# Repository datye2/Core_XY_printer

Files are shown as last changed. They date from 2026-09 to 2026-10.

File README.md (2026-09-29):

# CoreXY Printer

Bo điều khiển máy in 3D CoreXY và firmware tự viết cho nó. Không dùng Marlin, Klipper hay RepRapFirmware — toàn bộ từ parser tới bộ phát xung đều viết tay, chạy trên một MCU duy nhất.

## Phần cứng

| Thành phần | Lựa chọn |
|---|---|
| MCU | STM32H743IIT6, bo lõi FANKE FK743M2-IIT6 (480 MHz, HSE 25 MHz) |
| Driver X/Y | 2 × TMC2209, điều khiển qua UART một dây |
| Driver Z, E | 3 × A4988 (Z1, Z2, E) |
| Nguồn động lực | 24V |
| Công tắc hành trình | 3 cảm biến tiệm cận NPN, cách ly bằng PC817, Z kiêm dò bàn |
| MOSFET gia nhiệt | IRLB3034PbF, lái bằng TC4427 |

**Cơ khí:** đai GT2, puly 20 răng (40 mm mỗi vòng), vi bước 1/16 có nội suy, tức **80 bước/mm**.

## Cấu trúc thư mục

```
hardware/corexy_board/   sơ đồ KiCad 8 trang, BOM
hardware/tools/          script sinh và kiểm tra sơ đồ
software/CoreXY/         firmware STM32 (CubeMX + CMake)
  module/                code tự viết: tmc2209, stepper
  Core/                  code CubeMX sinh ra
  tools/flash_run.sh     nạp và chạy thử trong một lệnh
  debug/tmc.gdb          lệnh gdb hỗ trợ soi driver
docs/                    tài liệu dự án
```

Phần tự viết nằm hết trong `software/CoreXY/module/`. Mọi thứ khác trong `Core/` là do CubeMX sinh, chỉ sửa trong các vùng `USER CODE`.

## Sơ đồ chân chính

| Tín hiệu | Chân | Ghi chú |
|---|---|---|
| Motor A STEP / DIR | PD3 / PD4 | địa chỉ UART 0 (MS1 = 0, MS2 = 0) |
| Motor B STEP / DIR | PG9 / PG10 | địa chỉ UART 1 (MS1 = 1, MS2 = 0) |
| EN chung A + B | PA15 | mức thấp là bật |
| TMC UART | PB10 (TX qua 1k) + PB11 (RX) | USART3, một dây chung, có tiếng vọng |
| DIAG A / B | PD7 / PG11 | chưa dùng |
| LED báo sống | PH7 | nháy trong SysTick |

**Lưu ý:** MS1 và MS2 dùng làm địa chỉ UART, nên **vi bước phải cài qua UART**, không cài bằng chân được. Xem [docs/timer.md](docs/timer.md) và phần TMC2209 trong `module/tmc2209.c`.

## Build và nạp

```bash
cd software/CoreXY
cmake -S . -B build/Debug -G Ninja -DCMAKE_BUILD_TYPE=Debug   # lần đầu
cmake --build build/Debug
```

Nạp bằng OpenOCD với ST-Link:
```bash
openocd -f interface/stlink.cfg -f target/stm32h7x.cfg \
  -c "program build/Debug/CoreXY.elf verify reset" -c shutdown
```

Nạp rồi chạy thử một đoạn thẳng trong một lệnh:
```bash
./tools/flash_run.sh 20 0 20      # dx mm, dy mm, tốc độ mm/s
NOFLASH=1 ./tools/flash_run.sh 40 0 60
```

Debug trong VS Code: bấm F5, chọn **ST-Link (CoreXY)**. Live Watch đã bật sẵn, xem được biến trong lúc chip đang chạy.

## Tình trạng

| Phần | Tình trạng |
|---|---|
| Sơ đồ KiCad | Xong bản v0.1, chưa vẽ PCB |
| Cấu hình TMC2209 qua UART | Chạy thật, cả 2 driver |
| Phát xung một motor bằng timer | Xong |
| Hai motor, Bresenham, động học CoreXY | Xong, đã vẽ được hình vuông và hình tròn |
| Gia tốc hình thang | Chưa |
| Parser G-code | Chưa |
| Lookahead | Chưa |
| Homing, nhiệt độ, quạt | Chưa |

Chi tiết trong [docs/checklist.md](docs/checklist.md).

## Tài liệu

- [docs/timer.md](docs/timer.md) — bộ phát xung: timer, ngắt, Bresenham, ngân sách CPU.
- [docs/checklist.md](docs/checklist.md) — việc đã xong và việc còn lại.
- [docs/01_kinh_nghiem_tu_mach_tham_khao.md](docs/01_kinh_nghiem_tu_mach_tham_khao.md) — rút kinh nghiệm từ SKR2, Octopus Pro, Duet2, Prusa Buddy.

## Tham khảo

Đọc để học cách làm, không chép code: **grbl** (`planner.c`, `stepper.c`, `motion_control.c`), **grblHAL** (bản grbl có HAL, hỗ trợ STM32H7), **Marlin** (`planner.cpp`, `stepper.cpp`), **Klipper** (`kinematics/corexy.py`, `chelper/kin_corexy.c`), và app note **Atmel AVR446** về profile tốc độ động cơ bước.

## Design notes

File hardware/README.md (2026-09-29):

# Phần cứng bo điều khiển CoreXY

```
hardware/
├── corexy_board/              Project KiCad (mở corexy_board.kicad_pro bằng KiCad 10)
│   ├── corexy_board.kicad_sch Trang gốc: sơ đồ khối, quyết định thiết kế, bảng gán chân MCU
│   ├── 01_Nguon.kicad_sch     XT60, TVS, cầu chì, buck 5V, chống USB cấp ngược, NetTie GND
│   ├── 02_MCU.kicad_sch       2 header 2x28 của kit FK743M2-IIT6
│   ├── 03_Driver.kicad_sch    2x TMC2209 (MKS V2.0, UART) + 3x A4988 (Z1, Z2, E)
│   ├── 04_Heater.kicad_sch    TC4427 + IRLB3034 cho hotend, bed (+ MOSFET an toàn)
│   ├── 05_Quat.kicad_sch      2 kênh AO3400A + quạt bo luôn bật
│   ├── 06_NTC.kicad_sch       3 kênh NTC 100k
│   ├── 07_IO.kicad_sch        3 cổng cảm biến NPN cách ly PC817, cảm biến hết nhựa, UART SBC
│   ├── corexy.kicad_sym       Symbol riêng (header kit, TMC2209 MKS, module buck, power net)
│   ├── corexy_board.pdf       Bản in schematic
│   └── bom.csv                Danh sách linh kiện (gom theo giá trị)
└── tools/
    ├── gen_schematic.py       Mô tả mạch bằng Python -> sinh toàn bộ schematic
    ├── check_schematic.py     Chạy ERC + so netlist KiCad với kết nối mong muốn
    └── intent_netlist.json    Kết nối mong muốn (do gen_schematic.py ghi)
```

## Sửa mạch

Hai cách, **chọn một**:

1. **Sửa trong script** (khuyên dùng khi còn đổi nhiều): sửa `tools/gen_schematic.py`, rồi
   ```
   cd hardware/tools
   python3 gen_schematic.py && python3 check_schematic.py
   ```
   `check_schematic.py` phải báo `0 lỗi so khớp`.
2. **Sửa tay trong KiCad**: từ lúc này **không chạy lại** `gen_schematic.py` nữa, vì nó ghi đè toàn bộ file.

## Quy ước net

- `GND` logic, `PGND` công suất (heater, quạt, cảm biến 24V), `MGND` motor → nối nhau 1 điểm qua `NT1`, `NT2`.
- `+24V_BED` / `+24V_HEAT` / `+24V_FAN` / `+24V_MOT` / `+24V_VMOT` / `+24V_SENS`: các nhánh sau cầu chì.
- `+5V` từ buck; `+5V_KIT` sau diode, cấp cho kit; `+3V3` lấy từ ổn áp trên kit.
- Chân nguồn nằm ngang được nối bằng global label cùng tên net nguồn (KiCad tự gộp với power symbol).

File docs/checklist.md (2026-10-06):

# Checklist dự án

Cập nhật: 2026-10-06

## Phần cứng

- [x] Chọn linh kiện chính: FK743M2-IIT6, 2 × TMC2209, 3 × A4988, IRLB3034, TC4427
- [x] Rút kinh nghiệm từ SKR2, Octopus Pro, Duet2, Prusa Buddy (xem `01_kinh_nghiem_tu_mach_tham_khao.md`)
- [x] Sơ đồ KiCad v0.1, 8 trang, sinh bằng `hardware/tools/gen_schematic.py`
- [x] Bo mẫu hàn tay, chạy được UART và hai motor
- [ ] Rà lại sơ đồ sau khi bo mẫu chạy ổn
- [ ] Vẽ PCB
- [ ] Đặt gia công và ráp bo thật

### Bài học từ bo mẫu, phải áp vào PCB

- **VIO của TMC2209 lấy 3.3V**, cùng mức với MCU. Cấp 5V thì ngưỡng mức 1 thành 3.5V, MCU xuất 3.3V không đủ.
- **Điện trở nối TX vào bus UART là 1k.** Thử 10k thì sườn tín hiệu chậm, phản hồi của driver về bị lệch bit.
- **Chân PDN_UART trên module StepStick có thể để hở**, phải hàn pad thì mới dùng UART được. Đây là thứ làm mất nhiều thời gian nhất khi dựng bo mẫu.
- **Dây SWD phải ngắn và xoắn với GND.** Chạy motor ở 80 mm/s từng làm đứt kết nối SWD và ST-Link rớt khỏi USB.

## Firmware

### Bước 0 — TMC2209 qua UART ✅

- [x] Driver UART một dây, xử lý tiếng vọng, CRC theo datasheet
- [x] Cấu hình GCONF (`pdn_disable`, `mstep_reg_select`, `i_scale_analog`)
- [x] Đặt vi bước 1/16 qua CHOPCONF.MRES, bật `intpol`
- [x] SENDDELAY = 2 vì có hai driver chung bus
- [x] Xác nhận lệnh ghi bằng IFCNT, kiểm tra chip bằng IOIN VERSION = 0x21
- [x] Timeout và khoảng nghỉ giữa gói tự tính theo baud
- [ ] Tự phát hiện driver bị reset (GSTAT bit 0) rồi nạp lại cấu hình
- [ ] Đặt dòng bằng phần mềm qua IHOLD_IRUN, thay cho biến trở VREF
- [ ] Chuyển sang SpreadCycle hoặc đặt TPWMTHRS khi chạy nhanh

### Bước 1 — Một motor bằng timer ✅

- [x] TIM2 ở 1 MHz, ngắt update
- [x] `stepper_move_a` với số bước và tốc độ
- [x] Đếm vị trí tuyệt đối, tự dừng khi hết bước
- [x] LED vẫn nháy khi motor quay, chứng tỏ CPU không bị chặn

### Bước 2 — Hai motor, Bresenham, CoreXY ✅

- [x] `stepper_move_xy(dx, dy, speed)` với phép biến đổi A = X+Y, B = X−Y
- [x] Bresenham trên một timer chung, hai motor cùng bắt đầu và cùng kết thúc
- [x] Chu kỳ tính theo chiều dài XY, không theo AB
- [x] Tính số bước từ đích tuyệt đối để không tích luỹ sai số
- [x] Bỏ vòng chờ trong ngắt, dùng compare channel CC1 hạ chân STEP
- [x] Ép sự kiện update khi nạp ARR vì ARR có preload
- [x] Thử thật: đường thẳng, hình vuông, hình tròn 72 đoạn, tất cả về đúng điểm xuất phát
- [ ] Đo lại tốc độ tối đa sau khi sửa ISR (lần trước đứt SWD ở 80 mm/s)

### Bước 3 — Gia tốc hình thang ✅

- [x] Mỗi block có 3 pha: tăng tốc, chạy đều, giảm tốc
- [x] Tính profile ngoài ngắt, trong ngắt chỉ còn truy hồi số nguyên AVR446
- [x] Biến dư giữ phần lẻ của phép chia nên sai số không tích luỹ
- [x] Đoạn ngắn tự chuyển thành profile tam giác
- [x] Trần 40 kHz mỗi motor, tốc độ vô lý bị trả về `STEPPER_ERROR`
- [x] `stepper_set_accel()`, mặc định 2000 mm/s²
- [x] Chạy thật 100 mm ở 150 mm/s hết 728 ms, khớp mô phỏng

### Bước 4 — Nhận lệnh 🔶

- [x] Parser `G0`, `G1`, `G2`, `G3`, `G4`, `G90`, `G91`, `G92`, `G21`, và `F`
- [x] Bỏ qua Z, E, M, S, T, N để file của slicer vẫn chạy được trên máy chỉ có XY
- [x] Bỏ chú thích `;` và `( ... )`
- [x] Tách lớp `motion_control`: `mc_line`, `mc_arc`, giữ vị trí tuyệt đối
- [x] `mc_arc` chia cung theo dung sai dây cung 0.002 mm, giống `mc_arc` của grbl
- [x] `tools/make_gcode.py` sinh file demo, `tools/gcode_to_header.py` nhúng vào flash
- [x] Chạy thật: 48 dòng, 0 lỗi, 9.4 giây, về đúng gốc
- [ ] Nhận lệnh qua UART hoặc USB CDC thay vì nhúng vào flash
- [ ] Trả `ok` sau mỗi dòng để host biết nhịp gửi
- [ ] Đọc file từ thẻ microSD

### Bước 5 — Hàng đợi và lookahead ✅

- [x] Ring buffer 16 block, producer là main loop, consumer là ngắt
- [x] Junction deviation kiểu grbl, `stepper_set_junction_deviation()`, mặc định 0.05 mm
- [x] Quét lùi rồi quét tới, không đụng block đang chạy
- [x] Nạp block kế tiếp ngay trong ngắt, timer không dừng giữa hai block
- [x] `i_offset`, `j_offset` nối liền đường dốc qua ranh giới block
- [x] Chạy thật: 100 mm chia 20 đoạn hết **728 ms**, bằng đúng khi đi một đoạn liền
- [ ] Đo lại trên đường tròn 72 dây cung (mô phỏng cho thấy nhanh hơn 3.6 lần)

### Sau đó ⬜

- [ ] Homing với 3 cảm biến tiệm cận, Z kiêm dò bàn
- [ ] Trục Z và đầu đùn trên A4988
- [ ] Đọc nhiệt độ NTC, vòng điều khiển PID cho hotend và bàn
- [ ] Điều khiển quạt
- [ ] Đọc file từ thẻ microSD
- [ ] Input shaping
- [ ] Chuyển phần planner sang SBC (dự tính xa)

## Công cụ và tài liệu

- [x] Build bằng CMake và Ninja
- [x] Debug VS Code với ST-Link qua OpenOCD, bật Live Watch
- [x] `debug/tmc.gdb`: lệnh `tmc`, `bus`, `reinit`, `trap`
- [x] `tools/flash_run.sh`: nạp và chạy thử trong một lệnh
- [x] Git repo, đẩy lên GitHub
- [x] `README.md`, `docs/timer.md`, `docs/checklist.md`
- [ ] Tài liệu về giao thức TMC2209 và những lỗi đã gặp
- [ ] Ảnh chụp bo mẫu và sơ đồ đấu dây

## Việc còn treo

1. **Tốc độ tối đa chưa đo lại.** Lần thử trước đứt SWD ở 80 mm/s, chưa rõ là nhiễu hay MCU reset. Chạy `NOFLASH=1 ./tools/flash_run.sh 40 0 80` rồi xem LED còn nháy không.
2. **Baud UART đang để 9600.** Đã thử thật ở 115200 và 250000 đều tốt, nên chỉnh CubeMX về 115200.
3. **`step_test_speed` trong `main.c` đang là 2000**, đơn vị mm/s nên sẽ trả về `STEPPER_ERROR`. Giá trị hợp lý là 20 tới 60.
4. **`HAL_UART_Init()` tắt chế độ FIFO.** Nếu đổi baud lúc chạy thì phải gọi lại `HAL_UARTEx_EnableFifoMode()`, nếu không tiếng vọng chỉ về được 1 byte.

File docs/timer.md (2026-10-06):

# Bộ phát xung: timer, ngắt và Bresenham

Tài liệu này mô tả cách `module/stepper.c` biến một lệnh "đi từ đây tới kia" thành xung STEP/DIR cho hai motor CoreXY.

## 1. Động học CoreXY

Trên CoreXY không có motor X và motor Y. Hai motor A và B cùng kéo đầu in, mỗi motor phụ trách một đường chéo 45°.

```
ΔA = ΔX + ΔY          ΔX = (ΔA + ΔB) / 2
ΔB = ΔX − ΔY          ΔY = (ΔA − ΔB) / 2
```

Hệ quả:

| Đầu in đi | Motor A | Motor B |
|---|---|---|
| +X | quay | quay cùng chiều |
| +Y | quay | quay ngược chiều |
| Chéo ↗ | quay gấp đôi | **đứng yên** |
| Chéo ↘ | **đứng yên** | quay gấp đôi |

Khi đi chéo, motor phải quay nhanh hơn đầu in **√2 lần**. Vì vậy giới hạn tốc độ phải đặt cho từng motor, không đặt cho đầu in.

## 2. Cấu hình TIM2

| Thông số | Giá trị | Lý do |
|---|---|---|
| Timer | TIM2 | 32 bit, đặt chu kỳ dài thoải mái khi chạy chậm |
| Clock kernel | 240 MHz (APB1 timer clock) | |
| Prescaler | 239 | 240 MHz / 240 = 1 MHz, tức **1 tick = 1 µs** |
| ARR | chu kỳ bước, tính bằng µs | đặt lại ở mỗi lệnh chạy |
| CCR1 | 2 | độ rộng xung STEP, µs |
| ARPE | bật | ARR có preload |

Vì tick là 1 µs nên ARR đọc thẳng ra chu kỳ bước, không phải quy đổi gì.

## 3. Hai ngắt cho mỗi bước

```
           update (ARR)                 compare (CC1)
                │                             │
 STEP  ─────────┘‾‾‾‾‾‾‾‾‾‾‾‾‾‾‾‾‾‾‾‾‾‾‾‾‾‾‾‾‾└───────────────
                │◄────────── 2 µs ───────────►│
                                              │◄─ phần còn lại của chu kỳ ─►│
         Bresenham,                      hạ cả hai
         nâng chân STEP                  chân STEP
```

- **Ngắt update**: cộng biến tích luỹ, motor nào tới lượt thì nâng chân STEP, cập nhật vị trí, giảm bộ đếm.
- **Ngắt compare CC1**: hạ cả hai chân STEP.

**Độ rộng xung do phần cứng timer đo**, CPU không chờ. Trong ngắt compare, code hạ cả hai chân mà không cần nhớ motor nào vừa bước, vì hạ một chân vốn đã thấp thì không tốn gì.

Cả hai ngắt đều vào `stepper_tim2_isr()`, gọi từ `TIM2_IRQHandler` trong `stm32h7xx_it.c`. Hàm này **tự xoá cờ**, nên `HAL_TIM_IRQHandler` chạy sau đó không thấy gì để làm và thoát ngay.

## 4. Bresenham

Một lệnh chạy có `n = max(|ΔA|, |ΔB|)` nhịp. Mỗi nhịp, motor nào có biến tích luỹ tràn thì bước:

```
err_a += |ΔA|;   nếu err_a >= n thì A bước, err_a -= n
err_b += |ΔB|;   nếu err_b >= n thì B bước, err_b -= n
```

Khởi tạo `err_a = err_b = n / 2` để các bước phân bố đều, mượt hơn so với khởi tạo bằng 0. Grbl cũng làm vậy.

Nhờ Bresenham, hai motor **luôn cùng bắt đầu và cùng kết thúc**, không cần hai timer.

## 5. Tính chu kỳ

```
length = hypot(dx, dy)          ← chiều dài trong XY, KHÔNG phải trong AB
duration = length / speed
period_us = duration × 10⁶ / n
```

Đây là chỗ dễ sai nhất. Nếu lấy chiều dài trong không gian AB thì tốc độ đầu in sẽ sai đúng bằng hệ số √2 ở các hướng chéo.

## 6. Ba chi tiết dễ vấp

**Xung cuối cùng.** Nếu tắt timer ngay khi hết bước thì ngắt compare không bao giờ tới, chân STEP kẹt ở mức cao. Cờ `stopping` giải quyết: ngắt update chỉ đánh dấu, ngắt compare hạ chân xong mới tắt timer.

**ARR có preload.** `ARPE = 1` nên ghi ARR chỉ có hiệu lực từ chu kỳ sau. Phải ép một sự kiện update bằng `TIM2->EGR = TIM_EGR_UG` để nạp ngay, nếu không chu kỳ đầu tiên của mỗi lệnh sẽ dùng giá trị của lệnh trước. Ở Bước 3 khi liên tục đổi ARR để tăng giảm tốc, chi tiết này càng quan trọng.

**Vị trí tính từ đích tuyệt đối.** Số bước cần đi được tính bằng
```
target_a = lroundf((x + y) × 80)      rồi   steps_a = target_a − pos_a
```
chứ không cộng dồn từng đoạn đã làm tròn. Nhờ vậy sai số không tích luỹ sau hàng nghìn đoạn. Grbl cũng tính như vậy.

## 7. Ngân sách CPU

Ước tính khoảng 1 µs cho cả hai ngắt cộng lại, sau khi bỏ vòng chờ.

| Tốc độ đầu in | Bước/s mỗi motor khi đi chéo | Tải CPU |
|---|---|---|
| 60 mm/s | 6.8 k | ~0.7% |
| 150 mm/s | 17 k | ~1.7% |
| 300 mm/s | 34 k | ~3.4% |

Trần cứng hiện tại là `MIN_PERIOD_US = 5`, tức **200 kHz mỗi motor**. Vượt quá thì `stepper_move_xy` trả về `STEPPER_ERROR`.

Phiên bản trước dùng vòng chờ 3 µs ngay trong ngắt, tốn khoảng 5 µs mỗi bước, tức gấp 5 lần.

## 8. Vì sao giữ vi bước 1/16

Bit `intpol` trong CHOPCONF đang bật, nên TMC2209 **tự nội suy 1/16 lên 1/256** bên trong. Dòng điện đã mượt đúng mức 1/256 trong khi MCU chỉ phải phát xung ở mức 1/16.

Tăng lên 1/32 hay 1/64 chỉ nhân tần số xung lên mà không thêm được độ mượt hay độ chính xác, vì mômen giữ của mỗi vi bước tỉ lệ với sin của góc và ở 1/16 đã chỉ còn khoảng 10%.

Đánh đổi duy nhất: nội suy gây sai lệch vị trí tới nửa vi bước, tức khoảng 6 µm, nhỏ hơn nhiều so với sai số của dây đai và khung máy.

## 9. API

```c
stepper_status_t stepper_init(void);
stepper_status_t stepper_move_xy(float dx_mm, float dy_mm, float speed_mm_s);
uint8_t  stepper_busy(void);
void     stepper_wait(void);          /* chỉ dùng để test */
int32_t  stepper_pos_a(void);
int32_t  stepper_pos_b(void);
float    stepper_pos_x(void);
float    stepper_pos_y(void);
void     stepper_tim2_isr(void);      /* gọi từ TIM2_IRQHandler */
```

`stepper_move_xy` trả về ngay, ngắt lo phần còn lại. Đang chạy mà gọi tiếp thì trả về `STEPPER_BUSY`.

## 10. Gia tốc hình thang

Mỗi block có ba pha: tăng tốc, chạy đều, giảm tốc. Tính trước ngoài ngắt, bằng số thực:

```
ticks_per_mm = n / length_mm
v_max = speed × ticks_per_mm        c_min  = 10⁶ / v_max
a     = accel × ticks_per_mm        ramp   = (v_max² − v_entry²) / (2a)
```

Trong ngắt chỉ còn công thức truy hồi số nguyên của **Atmel AVR446**:

```
tăng tốc:  c −= (2c + rest) / (4·(i + i_offset) + 1)
giảm tốc:  c += (2c + rest) / (4·(events_left + j_offset) + 1)
chạy đều:  c = c_min
```

`rest` giữ phần dư của phép chia nguyên nên sai số không tích luỹ. Nếu đoạn quá ngắn, hai dốc chồng lên nhau và profile tự thành **hình tam giác**, không bao giờ đạt tốc độ đặt. Đây là lý do máy in thật không chạy đúng tốc độ trong slicer ở các chi tiết nhỏ.

## 11. Lookahead

Hai lớp tách bạch:

| Lớp | Chạy ở | Số học | Việc |
|---|---|---|---|
| Planner | main loop | số thực | hàng đợi 16 block, tốc độ góc, hai lượt quét |
| Executor | ngắt | số nguyên | Bresenham, truy hồi AVR446, nạp block kế tiếp |

**Tốc độ qua góc** dùng mô hình junction deviation của grbl: góc giữa hai vector đơn vị quyết định tốc độ được phép, thẳng thì giữ nguyên, gập ngược thì về 0.

**Hai lượt quét** mỗi khi có block mới:
- Lùi: một block không được vào nhanh hơn mức còn phanh kịp để khớp tốc độ vào của block sau.
- Tới: cũng không được vào nhanh hơn mức block trước đẩy lên được.

Block mà ISR đang chạy không bao giờ bị sửa.

**Mẹo nối liền hai block:** `i_offset` và `j_offset` đặt tốc độ vào và ra lên đúng vị trí trên một đường dốc ảo xuất phát từ 0. Nhờ đó công thức truy hồi chạy tiếp liền mạch qua ranh giới block thay vì khởi động lại.

Đo trên máy thật, 100 mm ở 150 mm/s với gia tốc 2000:

| Cách gửi | Thời gian |
|---|---|
| 1 đoạn 100 mm | 728 ms |
| 20 đoạn 5 mm | 728 ms |
| 20 đoạn, nếu dừng ở mỗi điểm nối | 1633 ms (mô phỏng) |

Chia nhỏ không còn tốn gì. Với đường tròn 72 dây cung, mô phỏng cho thấy nhanh hơn **3.6 lần**.

## 12. Còn thiếu

- Parser G-code và lớp `motion_control` để chia cung tròn.
- Nạp lệnh từ thẻ nhớ hoặc USB.
- Input shaping.

Xem [checklist.md](checklist.md).

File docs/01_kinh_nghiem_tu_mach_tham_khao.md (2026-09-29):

# Kinh nghiệm thiết kế rút ra từ các bo máy in 3D có sẵn

> Mục đích: tổng hợp cách các bo thương mại/mã nguồn mở giải quyết từng khối mạch,
> rồi đối chiếu với kế hoạch của bo CoreXY (kit FK743M2-IIT6 + 2×TMC2209 + 2×A4988, 24V).
> Bạn đánh dấu `[x]` vào các mục đồng ý, ghi chú mục muốn đổi → sau đó mới vẽ KiCad.
>
> Ngày lập: 2026-09-16

---

## 0. Các bo đã tham khảo

Tất cả schematic gốc được lưu trong `docs/references/`.

| Bo | MCU | Nguồn schematic | Ghi chú |
|---|---|---|---|
| **BTT SKR 2** | STM32F407VGT6 | `BTT_SKR2_SCH.pdf` | Bo phổ biến tầm trung, có bài học lỗi Rev A |
| **BTT Octopus Pro V1.1** | STM32F446 / H723 | `BTT_OctopusPro_V1.1_SCH.pdf` | Bo lớn cho Voron (CoreXY), thiết kế nguồn tách nhánh rõ |
| **Duet 2 v1.06** | ATSAM4E8E | `Duet2_v1.06_SCH.pdf` | Phần cứng mở, nổi tiếng về độ tin cậy |
| **Prusa Buddy v1.0.0** | STM32F407 | `Prusa_Buddy_v1.0.0_SCH.pdf` | Bo của Prusa MINI, sản xuất số lượng lớn |
| FANKE FK743M2-IIT6 | STM32H743IIT6 | `FANKE_FK743M2-IIT6_SCH.pdf` | Kit MCU của mình |

---

## 1. Khối nguồn vào & phân phối

### Các bo khác làm gì

| Bo | Cách chia nguồn | Cầu chì | Bảo vệ |
|---|---|---|---|
| Octopus Pro | **3 đầu vào riêng**: MOTOR_POWER / POWER / BED_POWER | 3 cầu chì riêng (F1 motor, F3 logic+heater, F2 bed) | LED báo từng rail (VM, 12V, 3.3V) |
| Duet 2 | 1 đầu vào, chia 3 nhánh | **Bed 15A**, Extruder/Stepper/5V **7.5A**, Fan **1A** | Tụ lọc VIN cạnh MOSFET |
| Prusa Buddy | 1 đầu vào, chia 2 nhánh | Bed/heater **7.5A**, Motor **3A** | TVS + ferrite + 330µF trên nhánh motor |
| SKR 2 | 1 đầu vào | **10A** (logic+motor), **15A** (bed) riêng | **TVS SMAJ28A** trên VIN, ferrite 30Ω lên VMOT |

- **Buck 5V** của cả 4 bo đều dùng IC chịu áp vào cao: AOZ1284 (SKR 2), SY8368 (Octopus Pro), LM25011 (Buddy). → Khớp với quyết định **tránh MP1584 (28V max)**, dùng LM2596S/XL4015.
- **Chống USB cấp ngược (backfeed)**: SKR 2 có jumper *DC SEL* + diode **SS14** trên VUSB; Octopus Pro có jumper J68 + diode **SK34**. → Xác nhận cách làm diode SS34 đã chọn là đúng hướng.
- **Giám sát điện áp**: Buddy có cầu chia **10k/1k** đo nguồn bàn nhiệt (BED_MON); SKR 2 và Octopus có cổng **PWR-DET** (phát hiện mất điện) và **PS-ON** (bật/tắt nguồn ATX).
- **Đặt tên GND theo vùng**: SKR 2 dùng 3 net `GND` (logic) / `PGND` (công suất heater, fan) / `MGND` (motor) → lúc làm PCB biết ngay đường nào nối hình sao ở đâu.

### ⚠️ Bài học lỗi thực tế

- **RAMPS 1.4**: cầu chì **polyfuse 11A** cho bàn nhiệt chạy sát giới hạn (bàn 200×200 ăn 8–10A), MOSFET Rds(on) cao, đường đồng/pad mỏng → **nóng chảy đầu nối**. Cách sửa cộng đồng: thay MOSFET Rds(on) thấp hơn và thay polyfuse bằng **cầu chì ô tô dạng lưỡi**.
- **SKR 2 Rev A**: BTT thêm mạch "bảo vệ driver cắm ngược" bằng MOSFET đóng/cắt **đường GND của motor (MGND↔PGND)**. Chính MOSFET đó bị lỗi → **làm hỏng driver** mà nó định bảo vệ. Rev B phải đổi linh kiện; cách chữa tạm là nối tắt MGND với PGND.
  → **Không chèn MOSFET/cầu chì nhỏ vào đường GND của driver.** GND motor phải là đường liền, chắc.

### Áp dụng cho bo của mình

- [ ] Đầu vào **XT60** + **TVS SMBJ28A** + **1000µF/35V** ngay sau đầu vào
- [ ] 3 cầu chì lưỡi ô tô: **Bed 15A** / **Hotend + fan 5A** / **Motor + logic 5A**
- [ ] Nhánh motor: thêm **ferrite bead** (≥5A) như SKR 2 / Buddy *(tùy chọn)*
- [ ] Buck **LM2596S hoặc XL4015** module, đầu ra 5.2V + **470µF + TVS SMBJ5.0A** trên bo
- [ ] Diode **SS34** giữa buck và chân 5V của kit (chống backfeed USB)
- [ ] Cầu chia **100k/10k + 100nF** đo 24V vào ADC (phát hiện mất nguồn / quá áp)
- [ ] LED báo nguồn 24V / 5V / 3.3V
- [ ] Dùng 3 net GND riêng trên schematic: `GND`, `PGND`, `MGND`, nối nhau tại **1 điểm** (net-tie)
- [ ] Đường GND motor **không** qua MOSFET/cầu chì nào

---

## 2. Khối MOSFET heater (hotend + bàn nhiệt)

### Các bo khác làm gì

| Bo | MOSFET bàn nhiệt | MOSFET hotend | Mạch lái gate | R gate / R kéo xuống | Diode ở đầu ra | LED báo |
|---|---|---|---|---|---|---|
| Duet 2 | IPD036N04L (40V) | AOD4184A (40V) | **74HCT02 @5V** (cổng NOR) | 180Ω / — | Không | Có (4k7) |
| Octopus Pro | IPD036N04L (40V) | HY1904C (40V) | **CD4504B @12V** | 1kΩ / 10kΩ | **SS54** | Có (4k7) |
| Prusa Buddy | PSMN2R6-40YS (40V) | PSMN2R6-40YS (40V) | Level converter **@5V** | 100Ω / 100kΩ | **SK310A (100V/3A)** | Có (10k) |
| SKR 2 | HYG017N04LS1C2 (40V) | HY1904C2 (40V) | **74HCT365 @5V** | 10Ω / 100kΩ | Không | Có (4k7) |

**Nhận xét rút ra:**

1. **Cả 4 bo đều dùng MOSFET 40V, Rds(on) vài mΩ.** → IRLB3034 (40V, ~2mΩ) đã chọn là đúng loại.
2. **Không bo nào lái gate trực tiếp bằng 3.3V** — đều qua buffer 5V hoặc 12V. → Xác nhận cần TC4427 (hoặc buffer 74HCT).
3. **Diode ngược ở đầu ra heater**: Octopus Pro và Buddy có, SKR 2/Duet không. Lý do nên có: người dùng hay cắm tải cảm (quạt, bơm, van điện từ) vào cổng heater, và dây dài cũng có điện cảm. Rẻ, nên thêm.
4. **Tất cả đều có LED báo** trên từng đầu ra.
5. **Duet 2 có mẹo an toàn khi khởi động**: dùng cổng NOR 74HCT02, một cổng lấy 3.3V làm tín hiệu "cho phép" → khi rail 3.3V chưa lên (MCU chưa chạy) thì **tất cả heater bị ép TẮT**, dù chân MCU đang thả nổi.
6. Duet 2 đặt **tụ 10µF/35V sát MOSFET bàn nhiệt** (giữa V_BED và Source) để giảm nhiễu khi đóng cắt.

### Hai lựa chọn mạch lái gate cho bo mình

| | **TC4427** (đã đề xuất) | **74HCT365 / 74HCT244** (như SKR 2, Octopus) |
|---|---|---|
| Dòng lái gate | 1.5A đỉnh → đóng cắt nhanh | ~25mA → chậm hơn, vẫn đủ cho PWM heater tần số thấp |
| Số kênh | 2 kênh / IC | 6 (365) hoặc 8 (244) kênh / IC → **gom luôn cả quạt** |
| Nguồn | 4.5–18V | 5V |
| Đầu vào 3.3V | Được (VIH 2.4V) | Được (HCT: VIH 2.0V) |
| Giá / dễ mua | Đắt hơn | Rất rẻ, rất phổ biến |

### Áp dụng cho bo của mình

- [ ] MOSFET heater + bed: **IRLB3034PbF** (THT cho bo thử)
- [ ] Mạch lái gate: **TC4427 @5V** ☐ hoặc **74HCT365 @5V** (gom cả heater + quạt) ☐ ← *chọn 1*
- [ ] R gate **22–100Ω**, R kéo xuống ở gate **10kΩ**, R kéo xuống ở đầu vào buffer **10kΩ**
- [ ] **Diode SS54** song song ngược ở mỗi đầu ra heater (như Octopus Pro / Buddy)
- [ ] LED + **4.7kΩ** báo trạng thái mỗi đầu ra
- [ ] Tụ **10µF/35V** sát MOSFET bàn nhiệt (như Duet 2)
- [ ] *(Tùy chọn)* Khóa heater khi MCU chưa chạy kiểu Duet 2 (dùng chân OE của buffer nối với "MCU ready")
- [ ] Chân ngắt tổng bàn nhiệt (PA4 → relay/MOSFET phía cao) — *không bo nào ở trên có*, là lớp bảo vệ thêm của mình

---

## 3. Khối quạt

### Các bo khác làm gì

| Bo | MOSFET | Lái gate | R gate / R kéo xuống | Diode flyback | Chọn điện áp quạt |
|---|---|---|---|---|---|
| Duet 2 | **AO3400A** | Trực tiếp từ MCU | 1kΩ / 10kΩ | **Có** (DO-219AB) | Jumper 5V / V_FAN / VIN + cầu chì **1A** |
| Octopus Pro | **ES3400** (tương đương AO3400) | 74HCT365 @5V | 22Ω / 10kΩ | **Có** (SS2FH) | Jumper **từng quạt**: 5V / 12V / VIN |
| SKR 2 | **ES3400** | 74HCT365 @5V | 10Ω / 100kΩ | **Không** (chỉ có LED) | Không |
| Prusa Buddy | — | — | — | — | Có chân **đo tốc độ (TACH)** cho quạt |

**Nhận xét:**
- AO3400A/ES3400 là lựa chọn chuẩn cho quạt → khớp kế hoạch.
- Duet 2 lái AO3400A **trực tiếp bằng 3.3V** vẫn chạy tốt với quạt nhỏ → không bắt buộc buffer cho quạt.
- **Buddy đo tốc độ quạt (TACH)**: nếu quạt tản nhiệt hotend chết → nhựa bị nóng chảy ngược lên phía trên (heat creep) → firmware phát hiện được để dừng in.

### Áp dụng cho bo của mình

- [ ] 3 kênh quạt dùng **AO3400A**, R gate 100Ω, R kéo xuống 100kΩ
- [ ] Diode flyback **SS14/SS24** mỗi kênh (theo Duet/Octopus, không theo SKR 2)
- [ ] LED + 4.7kΩ báo mỗi kênh
- [ ] *(Tùy chọn)* Jumper chọn áp quạt **5V / 24V** mỗi kênh (nếu sau này dùng quạt 5V/12V)
- [ ] *(Tùy chọn)* Chân **TACH** cho quạt hotend (quạt 3 dây) → 1 GPIO + pull-up 10k lên 3.3V
- [ ] Cầu chì nhỏ **1–2A** cho nhánh quạt (như Duet 2)

---

## 4. Khối đo nhiệt độ (thermistor)

### Các bo khác làm gì — **SKR 2, Octopus Pro, Prusa Buddy dùng GẦN NHƯ Y HỆT nhau**

```
3.3V ──[4.7kΩ 1%]──┬──[2.37kΩ 1%]──┬──[2.37kΩ 1%]──┬── ADC MCU
                   │               │               │
             Đầu nối NTC       BAV99 (kẹp       [100nF]
                   │           về 3.3V & GND)      │
                  GND                             GND
```

- **4.7kΩ 1%** pull-up lên 3.3V
- **2 điện trở 2.37kΩ 1% nối tiếp**, điểm giữa có **BAV99** (2 diode kẹp lên 3.3V và xuống GND)
  → nếu dây NTC chạm dây heater 24V: điện trở đầu hạn dòng, BAV99 kẹp áp, điện trở sau bảo vệ tiếp chân ADC
- **100nF** sát chân ADC để lọc
- **Buddy** thêm **ferrite** trên đường GND trả về của NTC
- **Duet 2** ghi chú: *"All thermistors should be pulled up to ADVREF"* — pull-up lên chân **điện áp tham chiếu ADC** thay vì 3.3V chung → giá trị đo ổn định hơn khi 3.3V bị nhiễu
- **Octopus Pro** có thêm kênh **PT100/PT1000** qua **MAX31865** (cho hotend nhiệt độ cao)

> ⚠️ **Khác với đề xuất trước của mình** (1kΩ + 10µF). Thiết kế 4.7k / 2×2.37k / BAV99 / 100nF đã được kiểm chứng trên hàng trăm nghìn bo → **nên theo thiết kế này**.
>
> 📝 Ghi chú cho firmware sau này: tổng điện trở nối tiếp ~4.7kΩ + tụ 100nF → cần **thời gian lấy mẫu ADC dài** (sample time lớn) để đọc đúng.

### Áp dụng cho bo của mình

- [ ] 3 kênh NTC theo mạch chung ở trên: **4.7k 1% / 2×2.37k 1% / BAV99 / 100nF**
- [ ] Pull-up lên: **VREF của kit** (như Duet) ☐ hoặc **3.3V** (như BTT/Prusa) ☐ ← *chọn 1*
- [ ] *(Tùy chọn)* Ferrite trên GND trả về (như Buddy)
- [ ] *(Tùy chọn)* Chừa chỗ **MAX31865** cho PT1000 — hay để dành bản sau

---

## 5. Khối công tắc hành trình, probe, cảm biến

### Các bo khác làm gì

**Công tắc hành trình** (SKR 2 và Octopus Pro):
```
Đầu nối 3 chân: [+5V] [GND] [Tín hiệu]
                                 │
3.3V ──[10kΩ]────────────────────┤
                                 ├──[1kΩ (SKR 2) / 100Ω (Octopus)]──┬── MCU
                                                                    │
                                                                 [100nF]
                                                                    │
                                                                   GND
```
- Đầu nối cấp **+5V** để nuôi cảm biến quang/hall, nhưng tín hiệu được **kéo lên 3.3V**.

**Chân DIAG cho sensorless** — mẹo hay:
- SKR 2: **jumper nối DIAG của driver vào chính đường endstop** (X-DIAG ↔ XMIN).
- Octopus Pro: DIAG nối vào net endstop qua **100Ω**.
- → Không tốn thêm chân MCU; muốn sensorless thì cắm jumper + rút công tắc cơ.

**Probe** (Octopus Pro — rất đáng học):
- Cổng probe có **optocoupler EL357C** + điện trở **1kΩ 0.6W** → nhận được probe cảm ứng từ chạy **12–24V** mà không hại MCU.
- **Jumper chọn áp nuôi probe**: 5V / 12V / VIN.
- **Jumper pull-up 12kΩ** để dùng được cả probe loại **NPN** và **PNP**.
- Cổng **BLTouch** riêng 5 chân (5V, GND, servo, GND, tín hiệu).

**Khác:**
- Cổng **PWR-DET** (10k pull-up + 100Ω + 100nF) và **PS-ON** (SKR 2, Octopus).
- LED **Neopixel/RGB**: dùng **74LVC1G125 nuôi 5V** để nâng mức tín hiệu 3.3V → 5V (SKR 2, Octopus).

### Áp dụng cho bo của mình

- [ ] 3 cổng endstop X/Y/Z: đầu nối 3 chân (5V, GND, S) + **10k lên 3.3V + 1kΩ + 100nF**
- [ ] Thêm **diode ESD** (PESD3V3 hoặc tương đương) trên mỗi tín hiệu — *các bo trên không có, là lớp thêm*
- [ ] DIAG: **nối riêng vào PD7/PG11** (kế hoạch cũ) ☐ hoặc **jumper vào đường endstop như SKR 2** (tiết kiệm chân) ☐ ← *chọn 1*
- [ ] Cổng **BLTouch** riêng (5V, GND, servo PB1, GND, tín hiệu)
- [ ] Cổng **probe cảm ứng từ** có **optocoupler EL357/PC817** + jumper áp nuôi 5V/24V + jumper pull-up NPN/PNP
- [ ] Cổng **cảm biến hết nhựa** (giống endstop)
- [ ] *(Tùy chọn)* Cổng **Neopixel** với 74LVC1G125 @5V
- [ ] *(Tùy chọn)* Cổng **E-stop**

---

## 6. Khối driver động cơ

### Các bo khác làm gì

- **Tụ 100µF/35V** sát chân VM **mỗi** driver (tất cả các bo).
- **Điện trở kéo lên 10kΩ lên 3.3V ở chân EN** (SKR 2) → driver **mặc định TẮT** khi MCU đang khởi động/nạp code.
- **Header jumper chân MS1/MS2/MS3** cạnh mỗi socket (SKR 2 `XMS1`) → cùng một socket cắm được **A4988, DRV8825, TMC2209** chỉ bằng cách đổi jumper.
- SKR 2/Octopus có header chọn **chế độ UART/SPI** cho TMC.
- Octopus Pro có **header 4 chân nối song song** cổng động cơ Z → cắm 2 động cơ Z song song mà không cần tự chế dây.
- ⚠️ **SKR 2 Rev A**: mạch bảo vệ driver bằng MOSFET trên MGND bị lỗi → hỏng driver (xem mục 1).

### Áp dụng cho bo của mình

- [ ] **4 socket driver giống hệt nhau** (A, B, Z, E) + **1 socket Z2 dự phòng**
- [ ] Mỗi socket: **100µF/35V low-ESR + 100nF** sát VM
- [ ] **10kΩ kéo lên 3.3V ở chân EN** mỗi driver
- [ ] **Header jumper MS1/MS2/MS3** mỗi socket → socket nào cũng cắm được cả TMC2209 lẫn A4988
- [ ] Đường UART TMC: **1kΩ** từ TX xuống đường PDN_UART chung, jumper nối vào từng socket
- [ ] Nối **RESET ↔ SLEEP** cho A4988 (bằng jumper, vì TMC2209 dùng chân này khác)
- [ ] Cổng Z: **2 đầu nối 4 chân** cạnh nhau, đi dây sẵn theo kiểu **nối tiếp** ☐ / **song song** ☐ ← *chọn 1*
- [ ] **Không** làm mạch bảo vệ bằng MOSFET trên GND motor
- [ ] In rõ chiều cắm driver trên silkscreen (để PCB sau)

---

## 7. Giao tiếp, debug & phụ trợ

### Các bo khác làm gì

- **ESD USB**: SKR 2 dùng **USBLC6-2P6** trên D+/D−. → Kit FK743M2 **không có** ESD trên USB (đã kiểm tra schematic kit). Không sửa được trên kit, cần lưu ý khi cắm rút.
- **Test point** (Duet 2): chừa test point cho STEP/DIR/EN từng trục và tín hiệu PWM từng heater, quạt.
- **CAN** (Octopus Pro): transceiver + ESD **PESD2CAN** → dành cho board đầu in sau này.
- Octopus Pro có **còi (buzzer)** và cổng **EXP1/EXP2** cho màn hình.

### Áp dụng cho bo của mình

- [ ] Header UART cho **SBC sau này** (TX, RX, GND, 5V)
- [ ] Test point: 24V, 5V, 3.3V, VREF, GND, PGND, MGND, STEP/DIR của A & B, PWM heater
- [ ] *(Tùy chọn)* Chừa footprint **CAN transceiver** (TJA1051) + ESD
- [ ] *(Tùy chọn)* Buzzer báo lỗi (thermal runaway)
- [ ] Kit FK743M2 cắm qua **2 hàng header cái 28×2** để tháo rời được

---

## 8. Tóm tắt: thay đổi so với kế hoạch đã bàn

| # | Hạng mục | Kế hoạch cũ | Đề xuất mới (theo bo tham khảo) |
|---|---|---|---|
| 1 | Lọc NTC | 1kΩ + 10µF | **4.7k / 2×2.37k / BAV99 / 100nF** (SKR 2, Octopus, Buddy) |
| 2 | Đầu ra heater | Không diode | **Thêm SS54** (Octopus, Buddy) |
| 3 | Chân EN driver | Dựa vào pull-up nội PA15 | **10kΩ kéo lên ngoài** mỗi driver (SKR 2) |
| 4 | Socket driver | Cố định loại driver | **Jumper MS1–3** để đổi A4988 ↔ TMC2209 tự do (SKR 2) |
| 5 | Mạch lái gate | TC4427 | TC4427 **hoặc** 74HCT365 gom cả quạt (SKR 2, Octopus) — *cần chọn* |
| 6 | GND | 1 net GND | **3 net GND / PGND / MGND** nối 1 điểm (SKR 2) |
| 7 | Cổng probe | BLTouch | BLTouch **+ cổng opto cho probe 24V** (Octopus) |
| 8 | Quạt hotend | PWM | PWM **+ TACH** (Buddy) — *tùy chọn* |
| 9 | Cầu chì quạt | Chung nhánh 5A | **Cầu chì 1–2A riêng** (Duet 2) — *tùy chọn* |
| 10 | Tụ bàn nhiệt | Không | **10µF/35V sát MOSFET** (Duet 2) |

---

## 9. Các điểm cần bạn quyết định trước khi vẽ

1. Mạch lái gate: **TC4427** hay **74HCT365**?
2. Pull-up NTC lên **VREF** hay **3.3V**?
3. DIAG: **chân riêng** hay **jumper vào endstop**?
4. Hai động cơ Z trên 1 A4988: **nối tiếp** hay **song song**?
5. Các mục *(Tùy chọn)* nào muốn đưa vào bản schematic đầu tiên?

### ✅ Đã chốt (2026-09-16)

| # | Quyết định |
|---|---|
| 1 | Mạch lái gate heater: **TC4427 @5V** (quạt: AO3400A lái trực tiếp 3.3V như Duet 2) |
| 2 | Pull-up NTC lên **3.3V** |
| 3 | DIAG TMC2209 nối **chân MCU riêng** (PD7, PG11) |
| 4 | Trục Z: **2 driver A4988 riêng** cho Z1 và Z2 → tổng 5 driver: A, B (TMC2209) + Z1, Z2, E (A4988) |
| 5 | MOSFET heater + bed: **IRLB3034PbF** (40V, ≤2.0mΩ @4.5V, TO-220) — không cần tản nhiệt; hàng thay thế: IRL3705N + tản nhiệt nhỏ |
| 6 | Homing X, Y, Z: **cả 3 đều cảm biến tiệm cận NPN** (Z dùng làm probe) → **3 cổng giống hệt nhau, cách ly PC817, chỉ NPN (không jumper)**: 1.5kΩ 0.5W + LED báo nối tiếp + 1N4148 ngược song song LED opto; phía MCU pull-up 10k lên 3.3V + 1kΩ + 100nF. Nguồn cảm biến 24V qua **cầu chì PTC 500mA** riêng. Không làm cổng BLTouch |
| 7 | Tùy chọn: ✅ ferrite nhánh motor, ✅ cầu chì quạt 1–2A riêng, ✅ tụ 10µF sát MOSFET bed; ❌ TACH (quạt 2 dây), ❌ khóa heater kiểu Duet, Neopixel, E-stop, buzzer, CAN, MAX31865 |
| 8 | **Ngắt tổng bàn nhiệt**: IRLB3034 thứ 2 **nối tiếp phía GND**, lái bằng **TC4427 thứ 2** (PA4); kênh còn dư để dự phòng |
| 9 | Quạt (đều 2 dây 24V): **part fan PWM** (AO3400A), **hotend fan bật/tắt** (AO3400A), **board fan luôn bật** (không MOSFET) |
| 10 | Tải: bed ≤250W (cầu chì 15A, terminal 7.62), hotend 40–60W (cầu chì 5A, terminal 5.08), NTC 100k B3950 |
| 11 | Thêm: cổng **cảm biến hết nhựa** (PC6), **header UART cho SBC**, **test point** |
| 12 | Đầu nối: JST-XH 2.54 (motor, cảm biến, quạt, NTC), XT60 nguồn vào |
| 13 | **TMC2209 = MKS V2.0** (pinout shop Đức Huy khớp MKS): hàng logic từ EN: `EN, MS1, MS2, NC, PDN, CLK, STEP, DIR`; hàng nguồn: `VM, GND, 1B, 1A, 2A, 2B, VIO, GND`; DIAG là chân rời phía trên → nối **dây Dupont** vào header 2 chân trên bo |
| 14 | Socket **A, B (TMC2209)**: pin4 NC, **pin5 PDN → bus UART**, pin6 CLK để hở (clock nội), VIO = 3.3V; địa chỉ UART bằng MS1/MS2: **A = 0 (GND/GND)**, **B = 1 (3.3V/GND)**; bus: PB10 (TX) qua 1kΩ, PB11 (RX) nối thẳng bus |
| 15 | Socket **Z1, Z2, E (A4988)**: MS1–3 lên 3.3V (1/16), **RESET↔SLEEP bằng jumper tháo được** (rút jumper là cắm TMC2209 chế độ standalone được), VDD = 3.3V |
| 16 | Tất cả socket: EN kéo lên 10kΩ lên 3.3V, 100µF/35V + 100nF sát VM |

---

## Nguồn

- BTT SKR 2: https://github.com/bigtreetech/SKR-2
- BTT Octopus Pro: https://github.com/bigtreetech/BIGTREETECH-OCTOPUS-Pro
- Duet 2 hardware: https://github.com/Duet3D/Duet-2-Hardware
- Prusa Buddy board: https://github.com/prusa3d/Buddy-board-MINI-PCB
- FANKE FK743M2-IIT6: https://github.com/nr-electronics/STM32H743_FANKE 
- Lỗi SKR 2 Rev A: https://3dwork.io/en/skr-2-failure-rev-a/ và https://github.com/bigtreetech/SKR-2/issues/15
- Lỗi RAMPS 1.4 bàn nhiệt: https://reprap.org/wiki/RAMPS_1.4

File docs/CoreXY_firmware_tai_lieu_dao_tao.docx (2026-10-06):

Firmware điều khiển máy in 3D CoreXY

Tài liệu kỹ thuật và đào tạo

Từ nguyên lý động cơ bước tới bộ điều khiển chuyển động hoàn chỉnh

Vi điều khiển STM32H743IIT6 · Driver TMC2209 · Cơ cấu CoreXY

Toàn bộ firmware tự viết, mọi số liệu trong tài liệu đều đo trên máy thật

github.com/datye2/Core_XY_printer · tháng 10 năm 2026

# Mục lục

# 0. Giới thiệu

## 0.1 Tài liệu này viết cho ai

Tài liệu dành cho người biết lập trình C ở mức cơ bản và đã từng điều khiển một chân GPIO trên vi điều khiển, nhưng chưa từng học lý thuyết điều khiển chuyển động. Mọi khái niệm chuyên ngành sẽ được định nghĩa ngay tại chỗ nó xuất hiện lần đầu, kèm con số cụ thể của chính cỗ máy này, không để người đọc phải tra cứu nơi khác rồi quay lại.

Nội dung là toàn bộ quá trình xây dựng firmware cho một máy in 3D kiểu CoreXY, viết từ con số không, không dùng Marlin, Klipper hay RepRapFirmware. Mỗi chương tương ứng một bước phát triển đã thực hiện, theo đúng thứ tự thời gian, và mỗi bước đều kết thúc bằng phép đo trên phần cứng thật.

## 0.2 Cách đọc

- Chương 1 tới 3 là nền tảng: động cơ bước, timer, động học CoreXY, kiến trúc phần mềm. Nên đọc tuần tự, các chương sau đều dựa vào đây.
- Chương 4 tới 10 là các bước đã làm. Mỗi chương có cấu trúc giống nhau: vấn đề cần giải, nguyên lý, cách cài đặt, phép thử và số liệu.
- Chương 11 tới 13 là phương pháp làm việc, tổng hợp lỗi đã gặp, và phụ lục tra cứu.

Nguyên tắc xuyên suốt dự án: không viết một dòng code nào cho bước sau khi bước hiện tại chưa chạy được trên phần cứng thật và chưa có số đo chứng minh. Mọi con số trong tài liệu đều là số đo, không phải số ước lượng.

## 0.3 Cách học tài liệu này

Tài liệu này không viết để đọc một lượt rồi cất. Đọc suông thì sau một tuần chỉ còn nhớ vài thuật ngữ. Phần dưới là lộ trình đã tính sao cho mỗi buổi học đều kết thúc bằng một thứ chạy được trên máy.

### Ba nguyên tắc

1. Luôn mở code bên cạnh. Đọc một mục trong tài liệu, rồi mở ngay hàm tương ứng trong mã nguồn và đối chiếu. Hiểu thuật toán mà không nhận ra nó nằm ở dòng nào thì khi cần sửa vẫn bó tay. Phụ lục A sinh ra chính để làm việc này.
2. Dự đoán trước, đo sau. Trước mỗi lần nạp, viết ra giấy con số bạn nghĩ máy sẽ cho. Rồi mới chạy. Trùng thì kiến thức được xác nhận. Lệch thì bạn vừa tìm ra một chỗ mình hiểu sai, và đó mới là lúc học được nhiều nhất. Nếu chỉ chạy rồi gật gù thì não không ghi lại gì cả.
3. Phá có chủ đích. Cố tình làm hỏng một chi tiết, chạy, quan sát hậu quả, rồi sửa lại. Bỏ biến `rest` đi và nghe tiếng động cơ sẽ khắc sâu hơn mười lần đọc giải thích về nó.

Vì sao nguyên tắc 2 quan trọng nhất: não chỉ ghi nhớ mạnh khi có sai số dự đoán. Đọc rồi đồng ý là hoạt động thụ động. Dự đoán 600 ms rồi thấy máy chạy 539 ms buộc bạn phải đi tìm lý do, và lý do đó sẽ nhớ rất lâu.

### Lộ trình tám buổi

Mỗi buổi khoảng 60 tới 90 phút. Không nên nhảy cóc, vì các buổi sau dùng lại kết quả đo của buổi trước.

Buổi | Đọc | Mở file | Việc cần làm | Coi như hiểu khi
1 | Chương 1 | — | Tự tính steps/mm cho puly 16 răng và vi bước 1/32 | Giải thích được vì sao vi bước không làm máy chính xác hơn
2 | Chương 2 | stepper.c, hàm stepper_move_xy | Tự tính ΔA, ΔB cho năm hướng đi bất kỳ | Nói ngay được hướng nào thì motor nào đứng yên
3 | Chương 3 và 6, phụ lục A.1 | stepper.h, A.1 | Chạy tay Bresenham với ΔA = 7, ΔB = 4 trên giấy | Giải thích được vì sao phải volatile
4 | Chương 6, phụ lục A.4.11 | stepper.c, hàm ISR | Bài tập B.2 số 1 tới 3 | Chỉ ra được dòng nào phát xung, dòng nào đếm vị trí
5 | Chương 7 | stepper.c, load_block | Bài tập B.2 số 4 tới 7 | Tự tính được thời gian một lệnh chạy trước khi đo
6 | Chương 8, phụ lục A.4.6 | stepper.c, recalculate | Bài tập B.2 số 8 tới 10 | Giải thích được vì sao cần đủ hai lượt quét
7 | Chương 9 và 10 | gcode.c, comms.c | Tự viết một file G-code vẽ chữ cái đầu tên mình | Sửa được parser để thêm một lệnh mới
8 | Chương 11 và 12 | tools/ | Toàn bộ mục B.3, phá rồi sửa | Đoán được chỗ hỏng trước khi đo

### Cách tự kiểm tra đã hiểu thật chưa

Ba phép thử, làm được cả ba thì chắc chắn đã hiểu, không phải chỉ thấy quen mặt:

- Giải thích bằng lời, không nhìn tài liệu, cho một người không biết gì, trong hai phút. Chỗ nào bạn phải nói mơ hồ là chỗ chưa nắm.
- Vẽ lại sơ đồ từ trí nhớ. Ví dụ vẽ lại Hình 12 và nói rõ ranh giới đổi đơn vị nằm ở đâu, vì sao ở đó.
- Xoá một hàm nhỏ rồi viết lại từ đầu. Bắt đầu bằng `junctionspeed` hoặc `periodof`, chúng ngắn và độc lập. So với bản gốc xem khác chỗ nào.

### Bốn sai lầm thường gặp khi tự học firmware

Sai lầm | Vì sao hại | Làm thay thế
Đọc hết một lượt rồi mới động vào máy | quên gần hết trước khi tới phần thực hành | mỗi chương đọc xong là chạy ngay một phép thử
Chép code rồi chỉnh tới khi chạy | chạy được mà không biết vì sao, lần sau hỏng là bó tay | đọc hiểu rồi tự gõ lại, dù chậm hơn
Bỏ qua phần mô phỏng Python | mất công cụ kiểm tra rẻ nhất và nhanh nhất | mô phỏng trước mỗi lần nạp
Chỉ học khi mọi thứ chạy đúng | bỏ lỡ phần giá trị nhất là gỡ lỗi | chủ động phá theo mục B.3

Một mẹo nhỏ nhưng hiệu quả: ghi nhật ký học vào một file văn bản. Mỗi buổi viết ba dòng: hôm nay dự đoán gì, đo được gì, vì sao lệch. Sau tám buổi, đọc lại chính nhật ký đó sẽ thấy rõ mình tiến tới đâu, và những chỗ từng hiểu sai thường là những chỗ nhớ kỹ nhất.

## 0.4 Lịch học hai ngày đầu

Tài liệu có ba tầng, và thứ tự đọc quan trọng hơn người ta tưởng. Đọc code khi chưa nắm hệ thống thì chỉ thấy một đống chi tiết rời rạc; nắm hệ thống rồi thì đọc code nhanh hơn nhiều, vì mỗi dòng đã có chỗ để gắn vào.

Tầng | Nằm ở đâu | Trả lời câu hỏi | Đọc khi nào
Hệ thống | Chương 1, 2, 3 | Máy gồm những gì, ghép với nhau ra sao | trước tiên
Từng khâu | Chương 4 tới 10 | Mỗi khâu giải quyết vấn đề gì, vì sao cần | ngay sau đó
Code | Phụ lục A | Dòng nào làm việc đó | khi bắt đầu sửa code
Phương pháp | Chương 11, 12 | Làm việc và gỡ lỗi thế nào | khi gặp lỗi đầu tiên

### Ngày thứ nhất: hiểu hệ thống, khoảng 2 tiếng

Buổi | Thời lượng | Việc
1 | 60 phút | Đọc chương 1, 2, 3. Chương 3 có sơ đồ phân lớp, là bức tranh tổng thể
2 | 40 phút | Làm bài tập lần theo một dòng lệnh, bảng ngay bên dưới
3 | 20 phút | Vẽ lại sơ đồ phân lớp từ trí nhớ, chỉ ra ranh giới đổi đơn vị nằm ở đâu và vì sao ở đó

### Bài tập buổi 2: lần theo một dòng lệnh

Lấy đúng một dòng G-code và tự điền bảng dưới, không nhìn tài liệu. Điền được hết nghĩa là đã hiểu hệ thống.

G1 X10 Y10 F3000

Khâu | Nhận vào cái gì | Biến thành cái gì | Đơn vị làm việc
gcode.c
motion_control.c
planner
ISR
driver TMC2209 | | xung điện cho hai cuộn dây | ampe

### Ngày thứ hai: hiểu từng khâu, khoảng 2 tiếng

Buổi | Thời lượng | Việc
1 | 70 phút | Đọc nhanh chương 4 tới 10. Mỗi chương chỉ cần nắm ba điều: vấn đề gì, giải bằng cách nào, kết quả đo ra sao. **Bỏ qua mọi đoạn code** trong các chương này
2 | 40 phút | Làm bài tập B.2. Đây là bài tập về hành vi của hệ thống, không phải về code: chạy lệnh, đọc số, so với dự đoán
3 | 10 phút | Ghi nhật ký ba dòng

Chưa cần đọc phụ lục A trong hai ngày này. Để dành tới lúc bắt tay sửa code, và khi đó cũng chỉ mở đúng hai mục liên quan tới thứ đang làm.

Nếu thiếu thời gian: bỏ theo thứ tự nhật ký, rồi buổi 3 của ngày thứ nhất. Không bỏ buổi đọc chương 1, 2, 3 và buổi làm B.2, vì hai buổi đó là nền cho mọi thứ sau.

# 1. Nền tảng: động cơ bước và cách ra lệnh cho nó

## 1.1 Động cơ bước khác động cơ thường ở chỗ nào

Động cơ một chiều thông thường cứ cấp điện là quay liên tục, muốn biết nó quay được bao nhiêu phải gắn thêm cảm biến đo góc. Động cơ bước thì ngược lại: nó quay theo từng nấc rời rạc, và mỗi nấc có góc cố định do cấu tạo cơ khí quyết định.

Loại NEMA17 dùng phổ biến trong máy in 3D có 200 nấc cho một vòng, tức mỗi nấc 1.8 độ. Bên trong có hai cuộn dây đặt vuông góc nhau. Nam châm vĩnh cửu của rotor luôn bị kéo về hướng của từ trường tổng do hai cuộn tạo ra. Thay đổi dòng trong hai cuộn theo đúng trình tự thì từ trường quay, và rotor quay theo từng nấc.

Hệ hở (open loop): hệ điều khiển không có phản hồi về kết quả thực tế. Máy in 3D dùng động cơ bước chính là hệ hở: firmware đếm số xung đã phát ra và tin rằng động cơ đã quay đúng ngần ấy nấc, chứ không hề đo lại.

Ưu điểm của hệ hở là đơn giản và rẻ. Nhược điểm nằm ngay cạnh: nếu tải quá nặng hoặc lệnh quay quá nhanh, rotor không theo kịp từ trường và trượt bước. Không có cảm biến nên không ai phát hiện ra. Firmware vẫn tưởng mọi thứ bình thường, còn chi tiết in ra thì lệch.

Vì sao điều này quan trọng: phần lớn công sức trong tài liệu này, đặc biệt chương 7 về gia tốc, tồn tại chỉ để bảo đảm một điều: không bao giờ ra lệnh vượt quá khả năng vật lý của động cơ. Vì nếu vượt, sẽ không có lỗi nào được báo cả.

## 1.2 Hai sợi dây STEP và DIR

Vi điều khiển không đủ sức cấp dòng cho động cơ, nên có một mạch trung gian gọi là driver, ở máy này là TMC2209. Driver lo toàn bộ phần dòng điện và thứ tự cấp điện cho hai cuộn dây. Vi điều khiển chỉ cần nói chuyện với driver bằng hai dây:

- DIR (direction): một mức logic. 0 là quay một chiều, 1 là quay chiều ngược lại.
- STEP (còn gọi là PUL, pulse): mỗi lần chân này đi từ 0 lên 1, driver dịch động cơ đúng một vi bước. Mức 1 chỉ cần giữ khoảng 100 nano giây là driver nhận ra, dự án này dùng 2 micro giây cho chắc chắn.

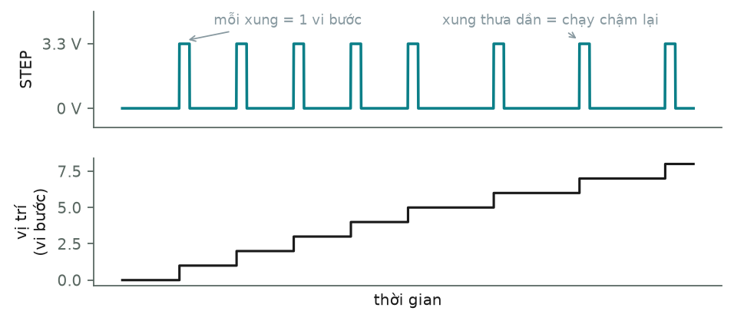
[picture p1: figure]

Hình 1 — Mỗi cạnh lên của tín hiệu STEP làm động cơ nhích một vi bước. Khoảng cách giữa hai xung quyết định tốc độ: xung mau là nhanh, xung thưa là chậm.

Toàn bộ nhiệm vụ của firmware, nói gọn lại, chỉ là phát xung STEP vào đúng thời điểm. Mọi chương sau đều xoay quanh câu hỏi: xung tiếp theo nên phát vào lúc nào.

Quan hệ giữa chu kỳ xung và tốc độ là nghịch đảo. Với máy này, 80 vi bước ứng với 1 mm:

Chu kỳ giữa hai xung | Tần số xung | Tốc độ đầu in
2000 µs | 500 Hz | 6.3 mm/s
625 µs | 1600 Hz | 20 mm/s
83 µs | 12000 Hz | 150 mm/s
25 µs | 40000 Hz | 500 mm/s, giới hạn của máy

## 1.3 Vi bước: chia nhỏ mỗi nấc

Nếu chỉ dùng 200 nấc nguyên cho một vòng, mỗi nấc là một cú giật, máy rung và ồn. Driver hiện đại khắc phục bằng cách không chuyển dòng đột ngột giữa hai cuộn, mà thay đổi dần theo dạng hình sin. Rotor khi đó dừng ở các vị trí trung gian giữa hai nấc cơ khí.

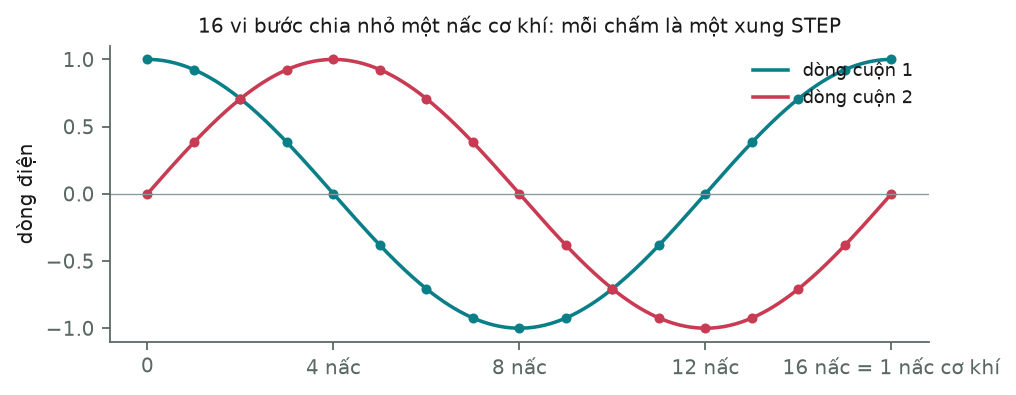
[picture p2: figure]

Hình 2 — Vi bước 1/16: dòng trong hai cuộn dây thay đổi theo hình sin lệch pha nhau 90 độ. Mỗi chấm tròn là một xung STEP, mười sáu chấm mới hết một nấc cơ khí.

Máy này dùng 1/16 vi bước, tức một vòng động cơ cần 200 × 16 = 3200 xung.

Nội suy (interpolation): TMC2209 có chức năng tự chia nhỏ thêm: nhận xung ở mức 1/16 nhưng bên trong tự sinh ra các bước trung gian cho tới mức 1/256. Vi điều khiển chỉ phải phát 3200 xung mỗi vòng, nhưng dòng điện mượt như thể 51200 xung.

Hiểu đúng về vi bước: vi bước làm chuyển động mượt hơn, không làm máy chính xác hơn. Mômen giữ của một vi bước tỉ lệ với sin của góc lệch, nên ở mức 1/16 thì mỗi vi bước chỉ còn khoảng 10% mômen. Chia nhỏ hơn nữa thì ma sát trong máy nuốt hết phần lực đó, rotor không thực sự dừng đúng vị trí được chỉ định. Đây là lý do dự án giữ 1/16 chứ không tăng lên 1/32 hay 1/64.

## 1.4 Hằng số quy đổi: 80 bước cho mỗi milimét

Người dùng ra lệnh bằng milimét, động cơ hiểu bằng số xung. Cầu nối là cơ cấu truyền động. Máy này dùng dây đai GT2 bước răng 2 mm, puly 20 răng:

chu vi puly = 20 răng × 2 mm = 40 mm cho mỗi vòng quay

số xung/vòng = 200 nấc × 16 = 3200 xung

steps_per_mm = 3200 / 40 = 80 xung cho mỗi milimét

độ phân giải = 1 / 80 = 0.0125 mm = 12.5 micromét

Con số 80 xuất hiện xuyên suốt tài liệu. Nó cũng cho biết giới hạn vật lý của máy: không có cách nào ra lệnh di chuyển nhỏ hơn 12.5 micromét.

## 1.5 Timer và ngắt: cách giữ nhịp chính xác

Cách phát xung ngây thơ nhất là dùng vòng lặp kèm hàm trễ. Cách này hỏng vì hai lý do: CPU bị chiếm hoàn toàn nên không làm được việc gì khác, và thời gian trễ không chính xác vì phụ thuộc vào việc trình biên dịch tối ưu ra sao.

Timer: một bộ đếm chạy bằng phần cứng, hoàn toàn độc lập với CPU. Nó đếm lên theo một xung clock cố định. Khi đếm tới một giá trị định trước, nó phát tín hiệu báo. Vì chạy bằng phần cứng nên thời gian chính xác tuyệt đối, không bị ảnh hưởng bởi CPU đang bận gì.

Ngắt (interrupt): tín hiệu yêu cầu CPU tạm dừng việc đang làm, nhảy sang chạy một hàm riêng, xong thì quay lại đúng chỗ cũ như chưa có gì xảy ra. Hàm đó gọi là trình phục vụ ngắt, viết tắt ISR (Interrupt Service Routine).

Nhờ hai cơ chế này, phát xung trở thành: nạp vào timer khoảng thời gian cần chờ, timer tự đếm, tới lúc thì gọi ISR, ISR phát một xung rồi nạp khoảng thời gian cho xung kế tiếp. Giữa hai lần ngắt, CPU rảnh để làm việc khác.

### Cấu hình cụ thể của dự án

Thông số | Giá trị | Lý do chọn
Timer | TIM2 | bộ đếm 32 bit, đặt được chu kỳ rất dài khi chạy chậm mà không tràn
Clock vào timer | 240 MHz | clock của nhánh bus APB1 trong chip
Prescaler | 239 | 240 MHz chia cho 240 bằng 1 MHz, nên **một nhịp đếm đúng 1 micro giây**
ARR | thay đổi theo tốc độ | số nhịp giữa hai lần ngắt, cũng chính là chu kỳ xung tính bằng micro giây

ARR (Auto Reload Register): thanh ghi chứa giá trị mà timer đếm tới trước khi phát ngắt rồi quay về 0. Vì ở đây một nhịp là 1 micro giây, ARR đọc thẳng ra chu kỳ xung. ARR = 83 nghĩa là cứ 83 micro giây phát một xung.

Preload: cơ chế của phần cứng: khi ghi giá trị mới vào ARR, giá trị đó không có hiệu lực ngay mà được giữ trong một thanh ghi đệm, chỉ nạp vào thật khi chu kỳ hiện tại kết thúc. Nghe như phiền, nhưng lại đúng ý khi tăng giảm tốc: chu kỳ đang chạy không bị can thiệp giữa chừng, còn giá trị mới tự động áp dụng cho chu kỳ kế tiếp. Chỉ khi bắt đầu một lệnh chạy mới mới cần ép nạp ngay, bằng cách tạo một sự kiện cập nhật.

## 1.6 Luật bất thành văn khi viết ISR

Ở tốc độ cao, ISR phát xung chạy hơn 30 000 lần mỗi giây. Mỗi lần chạy chỉ được phép chiếm vài micro giây, nếu không toàn hệ thống sụp đổ. Các quy tắc áp dụng trong dự án:

- Không gọi hàm trễ, không chờ vòng lặp, không gọi hàm giao tiếp như UART hay USB.
- Không dùng số thực nếu tránh được. Lý do không chỉ là tốc độ: mỗi lần vào ngắt mà có dùng FPU, phần cứng phải cất thêm một tập thanh ghi, làm thời gian vào ngắt dài thêm và dao động.
- Mọi phép tính nặng, mọi căn bậc hai, đẩy hết lên vòng lặp chính và tính sẵn một lần cho mỗi lệnh chạy.
- Biến dùng chung giữa ISR và vòng lặp chính phải khai báo volatile, nếu không trình biên dịch có thể giữ giá trị trong thanh ghi và không bao giờ đọc lại từ bộ nhớ.

# 2. Động học CoreXY

## 2.1 Vấn đề: không có motor X, cũng không có motor Y

Máy in kiểu Cartesian thông thường có một motor lo trục X, một motor lo trục Y. Muốn đi theo X thì quay motor X. Đơn giản, nhưng có một nhược điểm: motor X phải di chuyển cùng với trục Y, nên khối lượng chuyển động lớn, hạn chế gia tốc.

CoreXY giải quyết bằng cách gắn cả hai motor cố định trên khung. Không motor nào phải di chuyển. Cái giá phải trả là cả hai motor cùng tham gia vào mọi chuyển động, thông qua hai vòng dây đai bắt chéo nhau.

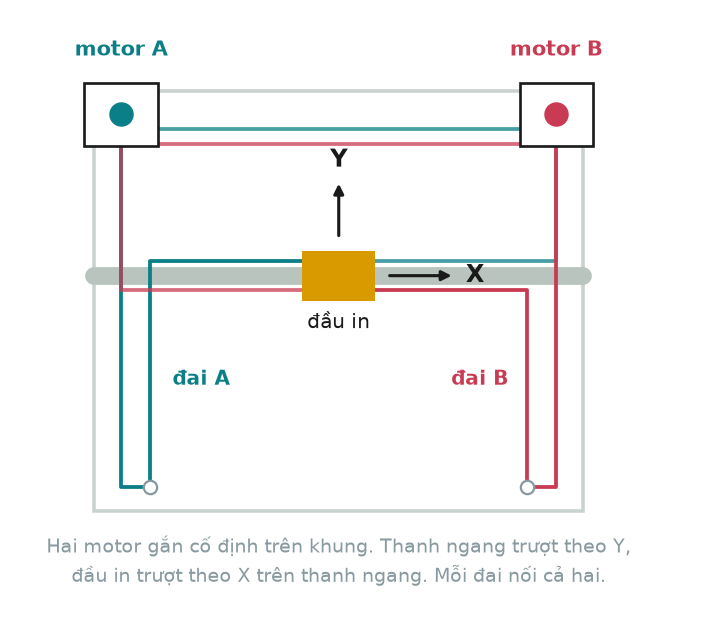
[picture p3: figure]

Hình 3 — Sơ đồ cơ cấu CoreXY nhìn từ trên xuống. Hai đai chạy qua các puly ở bốn góc và cùng nối vào đầu in.

## 2.2 Dẫn ra công thức từ nguyên lý dây đai

Chỉ cần một nguyên lý duy nhất: dây đai không co giãn.

Mỗi vòng đai có hai đầu gắn vào đầu in, ở giữa quấn qua puly của một motor. Nếu motor đứng yên, dây không thể trượt qua puly, nên chiều dài đoạn dây từ motor tới đầu in bị khoá cứng. Motor quay bao nhiêu milimét thì đoạn dây đó dài ra hoặc ngắn đi đúng bấy nhiêu.

Bây giờ đi theo đoạn dây của motor A, từ puly tới đầu in. Nó gồm hai phần: một phần chạy dọc cạnh bên, chiều dài phụ thuộc vị trí của thanh ngang tức toạ độ Y; một phần chạy dọc thanh ngang tới đầu in, chiều dài phụ thuộc toạ độ X. Vậy:

L_A = X + Y + hằng số

L_B = Y − X + hằng số (đai B đối xứng gương, nên dấu của X ngược lại)

Đổi quy ước chiều dương của motor B, tức đảo dây DIR, thì được dạng quen thuộc. Đây là động học ngược, dùng khi biết đầu in cần đi đâu và muốn biết motor phải quay bao nhiêu:

ΔA = ΔX + ΔY

ΔB = ΔX − ΔY

Cộng và trừ hai vế sẽ ra động học thuận, dùng để biết đầu in đang ở đâu:

ΔX = (ΔA + ΔB) / 2

ΔY = (ΔA − ΔB) / 2

Về dấu cộng trừ: dấu có thể khác tuỳ cách đi dây và chiều lắp motor. Nếu máy chạy ngược, chỉ cần đảo chân DIR hoặc hoán đổi vai trò A và B. Bản chất không đổi: một motor ứng với tổng X + Y, motor kia ứng với hiệu X − Y.

## 2.3 Bốn chuyển động cơ bản

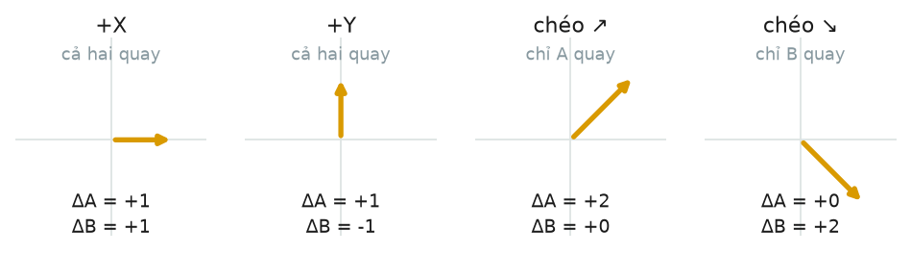
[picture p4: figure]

Hình 4 — Áp công thức cho bốn hướng tiêu biểu. Ở hai hướng chéo, một trong hai motor đứng yên hoàn toàn.

Kiểm chứng bằng tay cũng ra kết quả này. Đẩy đầu in sang phải mà giữ thanh ngang đứng yên: đoạn đai A trên thanh ngang dài ra, đoạn đai B ngắn lại, nên hai puly quay cùng chiều. Đẩy thanh ngang tiến lên mà đầu in đứng yên trên thanh: cả hai đoạn dọc đều ngắn đi, nhưng vì hai motor đối xứng gương nên hai puly quay ngược chiều nhau.

## 2.4 Một đường thẳng trong XY vẫn là đường thẳng trong AB

Phép biến đổi giữa hai hệ toạ độ là tuyến tính: mỗi toạ độ mới chỉ là tổng hoặc hiệu của hai toạ độ cũ, không có phép nhân hay luỹ thừa nào. Đây là tính chất cực kỳ quan trọng về mặt phần mềm.

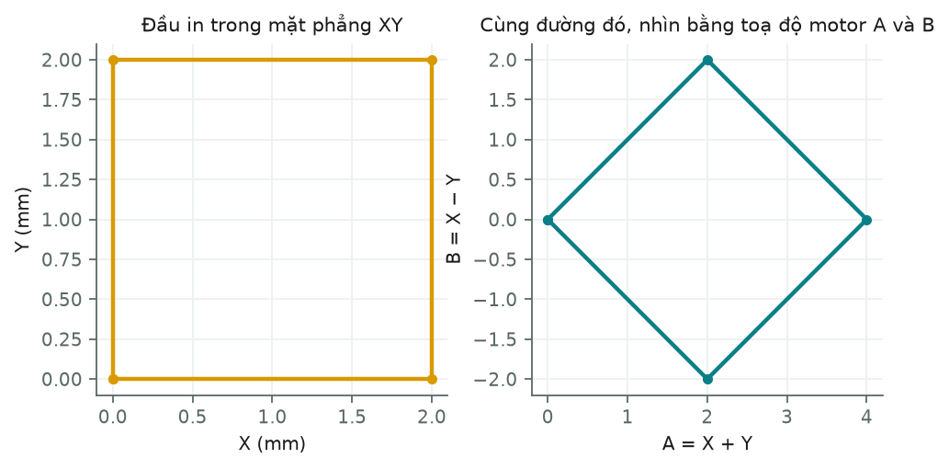
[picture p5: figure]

Hình 5 — Một hình vuông trong mặt phẳng XY, khi nhìn bằng toạ độ hai motor, trở thành hình vuông xoay 45 độ và phóng to. Các cạnh vẫn là đoạn thẳng.

Hệ quả thực tế: toàn bộ phần lập kế hoạch chuyển động, tính gia tốc, nội suy đoạn thẳng đều có thể làm trong hệ XY như máy thông thường. Chỉ cần đổi sang A và B ở bước cuối cùng, ngay trước khi phát xung. Nếu phép biến đổi không tuyến tính, như ở máy Delta, mọi thứ sẽ phức tạp hơn rất nhiều.

## 2.5 Hệ số căn hai và hệ quả

Khi đầu in đi chéo 45 độ, chỉ một motor làm việc nhưng motor đó phải quay nhanh hơn. Cụ thể, đi chéo một đoạn dài L thì ΔX và ΔY đều bằng L chia căn 2, nên ΔA bằng tổng của chúng, tức L nhân căn 2.

Hướng đi | Quãng đường đầu in | Số bước của motor bận nhất | Tỉ lệ
Thẳng theo X hoặc Y | 100 mm | 8000 bước | 80 bước/mm
Chéo 45 độ | 100 mm | 11314 bước | 113 bước/mm

Hệ quả cần nhớ khi lập trình: mọi giới hạn về tốc độ và gia tốc phải đặt cho từng motor, không đặt cho đầu in. Nếu chỉ giới hạn tốc độ đầu in ở 300 mm/s, thì khi đi chéo motor sẽ phải chạy ở mức tương đương 424 mm/s và có thể vượt khả năng.

Một cách hình dung khác: CoreXY chính là một máy Cartesian bị xoay 45 độ. Motor A điều khiển trục chéo theo hướng này, motor B điều khiển trục chéo theo hướng kia.

# 3. Kiến trúc phần mềm

Trước khi viết dòng code nào cần quyết định chia phần mềm thành những lớp nào. Chia đúng thì mỗi lớp chỉ phải biết một việc, và sửa lớp này không làm hỏng lớp kia.

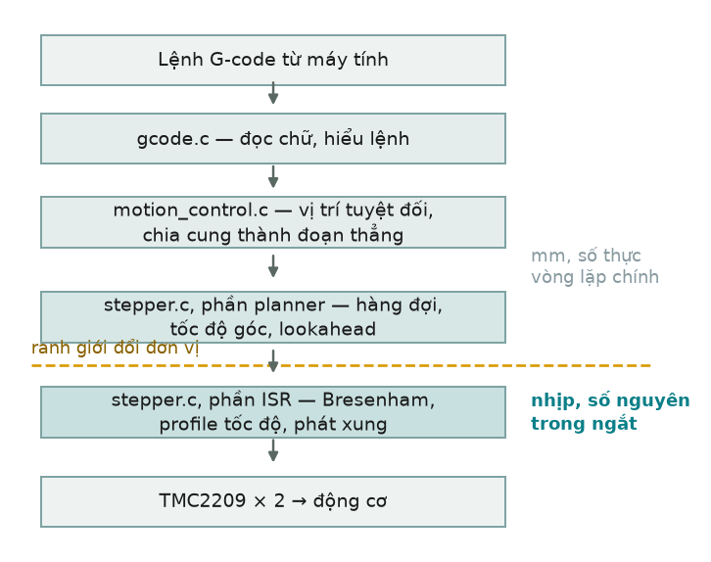
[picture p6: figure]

Hình 6 — Năm lớp của firmware. Ranh giới quan trọng nhất là đường nét đứt: phía trên dùng milimét và số thực, phía dưới dùng nhịp timer và số nguyên.

Lớp | Chạy ở đâu | Đơn vị | Kiểu số | Được phép chậm
gcode.c | vòng lặp chính | mm | số thực | được
motion_control.c | vòng lặp chính | mm | số thực | được
stepper.c, phần planner | vòng lặp chính | mm, mm/s | số thực | được
stepper.c, phần ISR | ngắt timer | nhịp, µs | **số nguyên** | **tuyệt đối không**

Chỗ đổi đơn vị nằm gọn trong đúng một hàm, gọi là `load_block`, chạy một lần mỗi khi bắt đầu một đoạn chuyển động mới. Nhờ vậy, khi đọc code ISR không bao giờ phải tự hỏi biến này đang tính bằng đơn vị gì.

# 4. Bước 0: cấu hình driver TMC2209 qua UART

## 4.1 Vì sao bắt buộc phải có bước này

TMC2209 có hai chân MS1 và MS2 để chọn mức vi bước bằng cách nối lên nguồn hoặc xuống mát. Nhưng trong thiết kế này, hai chân đó đã bị dùng cho việc khác: đặt địa chỉ cho driver, vì hai driver dùng chung một đường dây giao tiếp.

Hậu quả: nếu không làm gì thêm, driver A chạy ở mức 1/8 còn driver B chạy 1/32, lệch nhau bốn lần. Với CoreXY thì hai motor phải phối hợp chặt chẽ, lệch như vậy nghĩa là vẽ hình vuông sẽ ra hình méo xiên. Bắt buộc phải cài vi bước bằng phần mềm, qua UART.

## 4.2 UART và đường truyền một dây

UART: giao thức truyền dữ liệu nối tiếp đơn giản nhất. Mỗi byte được gửi thành một chuỗi mức điện áp: một bit khởi đầu, tám bit dữ liệu, một bit kết thúc. Hai bên phải thống nhất trước tốc độ truyền, gọi là baud, ví dụ 115200 baud nghĩa là 115200 bit mỗi giây. Không có dây clock, hai bên tự đếm thời gian, nên sai lệch tốc độ quá 2% là hỏng.

TMC2209 dùng một biến thể đặc biệt: chân PDN_UART vừa nhận vừa gửi trên cùng một sợi dây. Vi điều khiển nối chân phát qua một điện trở 1k rồi chung với chân thu vào sợi đó:

PB10 (TX) ──[1k]──┬── PDN_UART driver A, địa chỉ 0

├── PDN_UART driver B, địa chỉ 1

PB11 (RX) ────────┘

Hệ quả của việc dùng chung dây: mọi byte vi điều khiển gửi đi đều vọng ngược lại chân thu của chính nó. Khi đọc một thanh ghi, firmware nhận về 12 byte: 4 byte vọng của gói vừa gửi, rồi mới tới 8 byte trả lời của driver. Phải bỏ 4 byte đầu. Điện trở 1k có nhiệm vụ giới hạn dòng khi hai bên cùng lái đường dây.

## 4.3 Cấu trúc gói tin và CRC

Gói đọc thanh ghi, vi điều khiển gửi 4 byte:

[0x05] [địa chỉ] [mã thanh ghi] [CRC]

Driver trả lời 8 byte:

[0x05] [0xFF] [mã thanh ghi] [D3] [D2] [D1] [D0] [CRC]

└─ dữ liệu 32 bit, byte cao trước ─┘

CRC: viết tắt của Cyclic Redundancy Check, một con số tính ra từ toàn bộ nội dung gói tin theo một công thức cố định. Bên gửi tính rồi đính kèm, bên nhận tính lại và so. Khớp thì gần như chắc chắn gói tin không bị lỗi đường truyền. CRC không phải để bảo mật, chỉ để phát hiện nhiễu. TMC2209 dùng CRC 8 bit và datasheet có sẵn đoạn code mẫu.

Byte đầu tiên luôn là 0x05, gọi là byte đồng bộ. Driver dựa vào nó để tự dò tốc độ baud: nó đo độ dài các bit trong byte này rồi tự chỉnh theo. Nhờ vậy không cần cấu hình baud cho driver, muốn đổi tốc độ chỉ cần sửa phía vi điều khiển.

## 4.4 Các thanh ghi đã cài và ý nghĩa

Thanh ghi | Giá trị đặt | Ý nghĩa
NODECONF | SENDDELAY = 2 | buộc driver chờ lâu hơn trước khi trả lời, bắt buộc khi có nhiều driver chung một bus, để chúng không nói chồng lên nhau
GCONF | 0x1C1 | bật ba bit: dùng chân PDN cho UART, lấy vi bước từ thanh ghi thay vì từ chân MS, và giữ dòng theo biến trở trên module
CHOPCONF | MRES = 4, intpol = 1 | chọn 1/16 vi bước và bật nội suy lên 1/256
GSTAT | ghi 0x7 | xoá ba cờ sự cố: vừa reset, lỗi driver, sụt áp bơm điện tích
IFCNT | chỉ đọc | bộ đếm số lệnh ghi thành công, dùng để xác nhận lệnh đã tới nơi
IOIN | chỉ đọc | trạng thái các chân, và 8 bit cao là mã phiên bản, luôn bằng 0x21 với TMC2209

Vì sao cần IFCNT: lệnh ghi qua UART không có phản hồi. Driver nhận được hay không, firmware không biết. IFCNT là bộ đếm tăng lên sau mỗi lệnh ghi hợp lệ, nên đọc nó trước và sau khi ghi, thấy tăng đúng số lần là biết chắc đã thành công. Đây là cách duy nhất để xác nhận.

## 4.5 Bốn lỗi đã gặp, không lỗi nào ở thuật toán

Bước này mất nhiều thời gian nhất cả dự án. Đáng chú ý là không có lỗi nào nằm ở phần tính toán:

4. Chân PDN_UART trên module chưa thông. Nhiều module StepStick để hở chân này, phải hàn một mối nối trên bo mạch thì mới dùng được UART. Triệu chứng đánh lừa: tiếng vọng vẫn về đủ 4 byte nên tưởng dây tốt, nhưng thực ra tiếng vọng chỉ chạy vòng trong vi điều khiển, chưa từng tới driver.
5. Điện trở 10k thay vì 1k. Điện trở lớn làm sườn tín hiệu lên chậm, byte trả lời của driver bị lấy mẫu sai thời điểm, nhận về rác kiểu 0x50 thay vì 0x05. Để ý 0x50 chính là 0x05 bị dịch bit, dấu hiệu kinh điển của lấy mẫu sai.
6. Timeout để cứng 5 mili giây trong khi baud là 9600. Gửi 8 byte ở 9600 baud mất 8.3 mili giây, tức hết giờ trước cả khi gửi xong. Đã sửa thành tự tính theo baud hiện hành.
7. Không có khoảng nghỉ giữa hai gói. Datasheet ghi rõ driver còn giữ đường dây thêm bốn bit sau khi trả lời xong. Gửi gói kế tiếp ngay lập tức khiến hai bên cùng lái bus, byte nhận về bị lệch bit.

Bài học chung, áp dụng cho mọi giao thức: khi không chạy, đừng sửa thuật toán trước. Hãy đo xem tín hiệu có tới nơi không và đếm xem nhận được bao nhiêu byte. Một biến toàn cục ghi lại từng byte của lần giao tiếp cuối cùng đã giúp tìm ra cả bốn lỗi trên.

# 5. Bước 1: một động cơ quay bằng timer

Mục tiêu nhỏ và rõ ràng: một động cơ quay đúng số bước được yêu cầu, xung do ngắt timer phát ra, và CPU vẫn rảnh để làm việc khác.

## 5.1 Cấu trúc chương trình

stepper_move_a(steps, speed): // chạy ở vòng lặp chính

đặt chân DIR theo dấu của steps

chờ 10 µs cho DIR ổn định

steps_remaining = |steps|

ARR = 1000000 / speed // chu kỳ, tính bằng µs

bật timer kèm ngắt

ISR, mỗi lần ngắt là một bước:

bật chân STEP lên 1

hạ chân STEP xuống 0

position += chiều

steps_remaining--

nếu steps_remaining == 0 thì tắt timer

Vì sao phải chờ sau khi đặt DIR: driver cần một khoảng thời gian ngắn để chốt mức DIR trước khi nhận xung STEP. Nếu đổi chiều rồi phát xung ngay lập tức, bước đầu tiên có thể đi sai chiều.

## 5.2 Phép thử và cách đọc kết quả

- Chạy 1600 bước ở 1600 bước mỗi giây, tức 20 mm ở 20 mm/s. Động cơ phải quay rồi dừng đúng lúc, không quay thêm.
- Biến đếm vị trí phải đúng bằng 1600 sau khi chạy xong.
- Đi 20 mm rồi về 20 mm, vạch dấu bút trên puly phải trở lại đúng chỗ cũ. Đây là phép thử phát hiện mất bước.
- Phép thử quan trọng nhất: trong lúc động cơ quay, con LED nháy trong ngắt hệ thống vẫn phải nháy đều. Đó là bằng chứng CPU không bị chặn, tức kiến trúc dùng timer đã hoạt động đúng mục đích.

# 6. Bước 2: hai động cơ và thuật toán Bresenham

## 6.1 Bài toán cần giải

Đi một đoạn thẳng bất kỳ, hai motor thường phải đi số bước khác nhau. Ví dụ một đoạn cần motor A đi 8 bước còn motor B đi 3 bước. Hai motor phải cùng khởi hành, cùng về đích, và quan trọng hơn: ba bước của B phải rải đều trong suốt hành trình, chứ không phải dồn cục ở đầu hay cuối, nếu không quỹ đạo sẽ cong chứ không thẳng.

Cách làm sai thường thấy: cho mỗi motor một timer riêng, đặt tần số tỉ lệ với số bước. Hỏng vì hai timer không bao giờ đồng bộ hoàn hảo, và sai số tích luỹ theo thời gian.

Cách làm đúng: một timer duy nhất cho cả hai motor. Mỗi lần ngắt gọi là một nhịp. Trong mỗi nhịp, firmware quyết định motor nào bước, motor nào đứng yên.

## 6.2 Ý tưởng: bộ tích luỹ phần dư

Vấn đề quy về: phân bố đều 3 sự kiện vào 8 nhịp, chỉ dùng số nguyên. Nếu được dùng số thực thì đơn giản, cứ 8 chia 3 bằng 2.67 nhịp lại cho một bước. Nhưng 2.67 không phải số nguyên, và dùng số thực trong ISR thì vi phạm nguyên tắc ở mục 1.6.

Giải pháp là một bộ tích luỹ: mỗi nhịp cộng thêm một lượng cố định vào một biến đếm. Khi biến đó vượt ngưỡng thì phát một bước và trừ bớt ngưỡng đi. Phần dư được giữ lại, không bị vứt.

n = max(|ΔA|, |ΔB|) số nhịp của cả đoạn

err_a = err_b = n / 2 khởi tạo ở giữa

mỗi nhịp:

err_a += |ΔA|

nếu err_a >= n: motor A bước, err_a -= n

err_b += |ΔB|

nếu err_b >= n: motor B bước, err_b -= n

Motor đi nhiều bước hơn sẽ có số cộng vào bằng đúng n, nên nó bước ở mọi nhịp. Motor kia cộng ít hơn nên thỉnh thoảng mới đủ ngưỡng.

## 6.3 Chạy thử bằng tay

Với ΔA = 8 và ΔB = 3, nên n = 8. Bảng dưới là từng nhịp một, cột err là giá trị sau khi đã trừ ngưỡng:

Nhịp | err_b trước | cộng 3 | ≥ 8 ? | B có bước | err_b sau
1 | 4 | 7 | không | | 7
2 | 7 | 10 | có | ✔ | 2
3 | 2 | 5 | không | | 5
4 | 5 | 8 | có | ✔ | 0
5 | 0 | 3 | không | | 3
6 | 3 | 6 | không | | 6
7 | 6 | 9 | có | ✔ | 1
8 | 1 | 4 | không | | 4

Kết quả: B bước ở nhịp 2, 4 và 7. Đúng ba bước, và rải khá đều trong tám nhịp. Không có phép chia nào, không có số thực nào, chỉ cộng, so sánh và trừ.

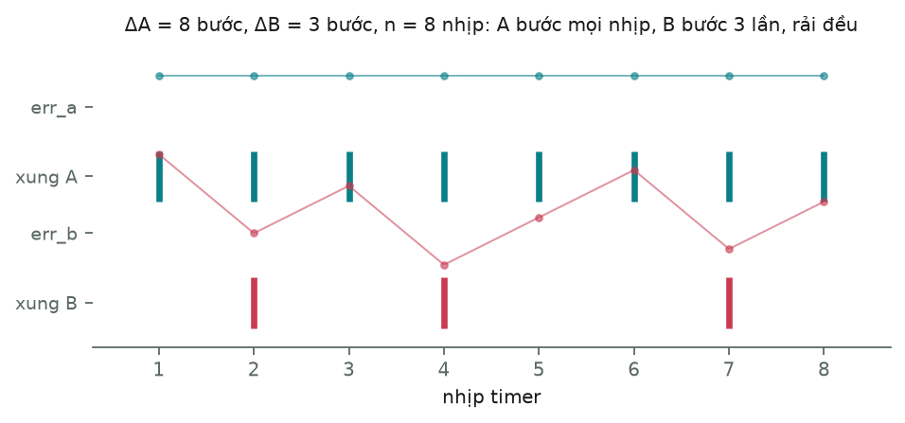
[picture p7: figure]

Hình 7 — Cùng ví dụ đó vẽ ra: motor A bước mọi nhịp, motor B bước ba lần rải đều. Đường mảnh là giá trị bộ tích luỹ, mỗi lần chạm ngưỡng thì rơi xuống và sinh một bước.

## 6.4 Vì sao gọi là Bresenham

Thuật toán này do Jack Bresenham công bố năm 1962 khi làm việc tại IBM, để giải một bài toán khác: vẽ một đoạn thẳng trên màn hình.

Màn hình chỉ có các điểm ở toạ độ nguyên. Muốn vẽ đoạn thẳng từ điểm (0,0) tới (8,3), máy phải chọn 8 điểm, mỗi cột x một điểm, sao cho dãy điểm đó bám sát đường thẳng lý tưởng nhất. Cột x nào thì y tăng lên một đơn vị? Chính là câu hỏi phân bố đều 3 lần tăng vào 8 cột.

Hai bài toán giống nhau về bản chất, nên dùng chung một lời giải. Điểm chung: phải chia một số nguyên cho một số nguyên khác mà không được dùng số thực, và không được vứt phần dư.

Triết lý đáng nhớ: không vứt phần dư, giữ lại dùng tiếp. Ý tưởng này sẽ xuất hiện lại lần nữa ở chương 7, trong biến `rest` của thuật toán gia tốc, dù đó là một bài toán hoàn toàn khác.

Chi tiết khởi tạo `err = n/2` thay vì 0: nếu khởi tạo bằng 0 thì bước đầu tiên của motor chậm sẽ tới muộn hơn một chút so với lý tưởng. Khởi tạo ở giữa làm các bước phân bố cân đối hơn, chuyển động mượt hơn. Grbl cũng làm như vậy.

## 6.5 Hai chi tiết dễ sai

8. Chiều dài đoạn phải đo trong mặt phẳng XY, không đo trong không gian AB. Nếu lấy nhầm, tốc độ đầu in sẽ sai đúng hệ số 1.41 ở các hướng chéo, mà lại đúng ở hướng thẳng, nên rất khó phát hiện.
9. Số bước phải tính từ toạ độ đích tuyệt đối, không cộng dồn từng đoạn đã làm tròn:

// Đúng: sai số làm tròn không bao giờ tích luỹ

target_a = lroundf((x_đích + y_đích) * 80);

steps_a = target_a - pos_a;

// Sai: mỗi đoạn mất một chút, hàng nghìn đoạn thì lệch thấy rõ

steps_a = lroundf((dx + dy) * 80);

## 6.6 Bỏ vòng chờ trong ngắt bằng kênh so sánh

Phiên bản đầu tiên bật chân STEP, chờ 2 micro giây bằng một vòng lặp rỗng, rồi hạ xuống. Chờ trong ngắt là lãng phí: CPU đứng im nhưng vẫn bị tính là bận, và không ai khác được chạy.

Kênh so sánh (compare channel): ngoài việc đếm tới ARR rồi phát ngắt, timer còn có thể phát thêm ngắt khi bộ đếm đi qua một giá trị trung gian. Đặt giá trị đó bằng 2 thì cứ 2 micro giây sau mỗi lần bắt đầu chu kỳ, một ngắt thứ hai được sinh ra. Dùng nó để hạ chân STEP, phần cứng đo thời gian thay cho CPU.

ngắt update (ARR) ngắt compare (CC1)

│ │

STEP ────────┘‾‾‾‾‾‾‾‾‾‾‾‾‾‾‾‾‾‾‾‾‾‾‾‾‾‾‾‾└──────────────

│◄────── 2 micro giây ──────►│

Bresenham, hạ cả hai chân

nâng chân STEP (hạ chân vốn đã thấp

của motor tới lượt thì không tốn gì)

Phiên bản | CPU tốn cho mỗi bước | Trần tốc độ mỗi motor
Vòng chờ trong ngắt | khoảng 5 µs | 100 kHz
Dùng kênh so sánh | khoảng 1 µs | 200 kHz

Chi tiết dễ bỏ sót: nếu tắt timer ngay khi hết bước thì ngắt so sánh không bao giờ tới, và chân STEP kẹt ở mức cao. Cần một cờ trạng thái: ngắt chính chỉ đánh dấu là sắp xong, ngắt so sánh hạ chân xuống rồi mới thật sự tắt timer.

# 7. Bước 3: gia tốc hình thang

## 7.1 Vì sao không thể chạy ngay ở tốc độ đích

Rotor và puly có khối lượng, nên có quán tính. Muốn tăng tốc độ quay thì cần mômen, mà mômen của động cơ bước có hạn. Nếu ra lệnh chạy 150 mm/s ngay từ xung đầu tiên khi đang đứng yên, từ trường quay đi trước còn rotor không theo kịp, kết quả là rotor rung tại chỗ và mất toàn bộ số bước.

Pull-in rate: tốc độ cao nhất mà động cơ bước có thể khởi động tức thời từ trạng thái đứng yên mà không mất bước. Với tải thực tế của máy này, giá trị đó nằm khoảng 30 tới 50 mm/s. Đó đúng là trần tốc độ của máy trước khi làm bước này.

Giải pháp là không bao giờ nhảy bậc, mà tăng tốc từ từ tới tốc độ mong muốn, rồi giảm dần trước khi dừng.

## 7.2 Hình dạng cần tạo và hai công thức

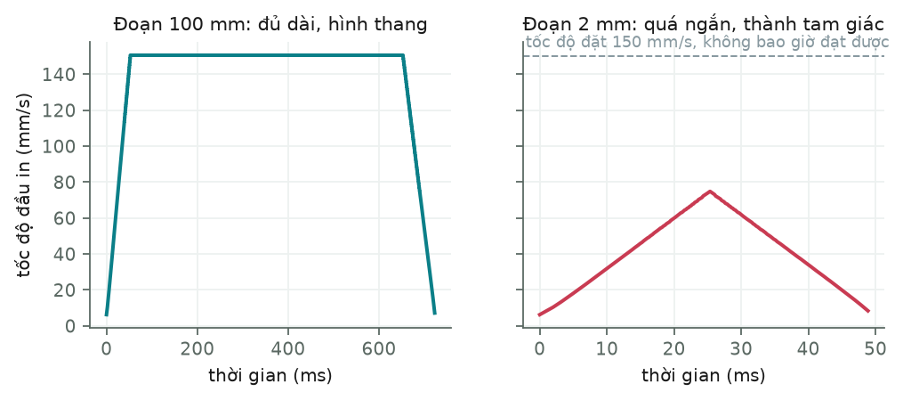
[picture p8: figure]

Hình 8 — Bên trái: đoạn đủ dài nên đạt được tốc độ đặt, đồ thị hình thang. Bên phải: đoạn quá ngắn, hai dốc gặp nhau trước khi kịp đạt tốc độ đặt, đồ thị thành hình tam giác.

Chỉ cần hai công thức vật lý phổ thông, áp dụng cho chuyển động gia tốc đều:

v = a · t tốc độ đạt được sau thời gian t

s = v² / (2a) quãng đường cần để đạt tốc độ v

Dẫn công thức thứ hai: t = v/a, s = ½at² = ½a(v/a)² = v²/(2a)

Thay số thật của máy, chạy 150 mm/s với gia tốc 2000 mm/s²:

thời gian tăng tốc = 150 / 2000 = 0.075 giây

quãng tăng tốc = 150² / (2 × 2000) = 5.6 mm

Vậy một hành trình 100 mm chia thành: 5.6 mm tăng tốc, 88.8 mm chạy đều, 5.6 mm giảm tốc.

## 7.3 Đổi sang không gian nhịp

ISR không biết milimét, cũng không biết giây. Nó chỉ biết nhịp timer và micro giây. Cần một tỉ số quy đổi, và tỉ số đó có sẵn trong mỗi lệnh chạy:

ticks_per_mm = n / length_mm

n số nhịp của đoạn, bằng max(|ΔA|, |ΔB|), đã tính sẵn cho Bresenham

length_mm quãng đường đầu in đi trong XY, bằng căn(dx² + dy²)

v_nhịp = v_mm × ticks_per_mm a_nhịp = a_mm × ticks_per_mm

Kiểm tra thứ nguyên cho thấy phép đổi là hợp lệ: milimét trên giây nhân với nhịp trên milimét thì milimét triệt tiêu, còn lại nhịp trên giây.

### Hệ số căn hai tự xuất hiện

Đây là điểm tinh tế đáng chú ý. Hai lệnh chạy cùng dài 3 mm nhưng khác hướng:

Lệnh chạy | ΔA | ΔB | n | length | ticks_per_mm
Thẳng 3 mm theo X | 240 | 240 | 240 | 3 mm | 80
Chéo 45 độ, cũng 3 mm | 339 | 0 | 339 | 3 mm | 113

Tỉ số 339 chia 240 bằng đúng 1.41. Hệ số căn hai xuất hiện mà không ai viết nó vào code, vì `n` đi qua phép biến đổi CoreXY nên mang theo đặc tính hình học của cơ cấu, còn `length_mm` thì không. Nếu sau này đổi sang cơ cấu khác, chỉ cần sửa công thức tính ΔA và ΔB, toàn bộ phần gia tốc không phải đụng tới.

## 7.4 Dãy chu kỳ và công thức truy hồi

Tăng tốc nghĩa là mỗi bước có chu kỳ ngắn hơn bước trước. Cần một dãy số c₀, c₁, c₂... Công thức chính xác suy ra từ quãng đường theo thời gian:

n = ½·a·t² → t_n = căn(2n / a) thời điểm bước thứ n xảy ra

c_n = t_(n+1) − t_n = căn(2/a) · (căn(n+1) − căn(n))

Công thức này đúng tuyệt đối nhưng chứa căn bậc hai, không thể chạy hàng chục nghìn lần mỗi giây trong ISR. Thuật toán của Atmel, công bố trong tài liệu ứng dụng AVR446, khai triển tỉ số hai chu kỳ liên tiếp và được xấp xỉ rất gọn:

c_n 2

─────── ≈ 1 − ────── → c_n = c_(n−1) − 2·c_(n−1) / (4n + 1)

c_(n−1) 4n+1

Chỉ còn một phép nhân hai, một phép chia và một phép trừ. Căn bậc hai duy nhất còn lại là ở bước đầu tiên, và nó chạy một lần cho cả lệnh chạy, ở vòng lặp chính.

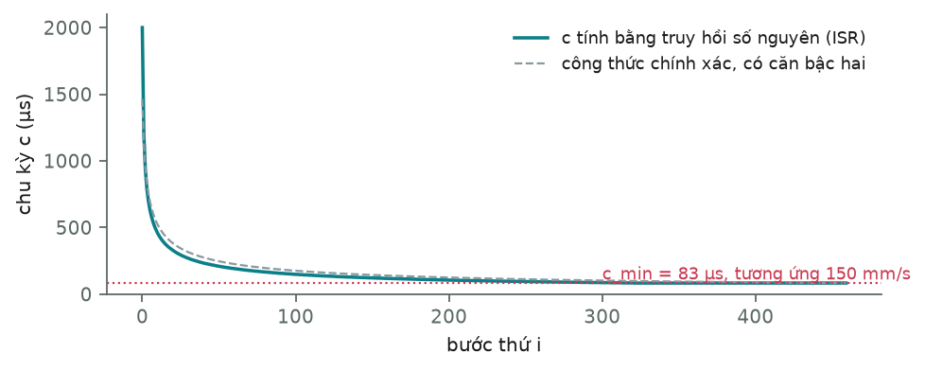
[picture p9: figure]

Hình 9 — Dãy chu kỳ do công thức truy hồi số nguyên sinh ra, so với công thức chính xác có căn bậc hai. Hai đường gần như trùng nhau.

Đọc đồ thị: chu kỳ co từ 2000 micro giây xuống 83 micro giây sau 450 bước, đúng bằng số nhịp tăng tốc đã tính. Lúc đầu giảm rất mạnh, càng về sau càng ì, vì tốc độ tăng theo căn bậc hai của quãng đường.

Bước thứ | Chu kỳ c | Tốc độ tương ứng
0 | 2000 µs | 6.2 mm/s
1 | 1200 µs | 10.4 mm/s
2 | 934 µs | 13.4 mm/s
5 | 631 µs | 19.8 mm/s
11 | 437 µs | 28.6 mm/s
450 | 83 µs | 150.6 mm/s

Vì sao chu kỳ đầu tiên bị chặn ở 2000 µs: công thức cho c₀ bằng 3536 micro giây, tương ứng 3.5 mm/s. Khởi động chậm như vậy là phí thời gian vì động cơ thừa sức bắt đầu ở 6 mm/s. Chặn lại giúp rút ngắn vài chục mili giây cho mỗi lệnh chạy.

## 7.5 Biến rest: chi tiết nhỏ quyết định thành bại

Phép chia trong ngôn ngữ C giữa hai số nguyên luôn cắt bỏ phần lẻ. Ở đây việc cắt bỏ không gây sai số nhỏ, mà làm hỏng hẳn thuật toán. Xét lúc đang ở nhịp 400 với chu kỳ 90 micro giây:

num = 2 × 90 = 180 den = 4 × 400 + 1 = 1601

180 / 1601 = 0 phần nguyên bằng không

Không có cơ chế giữ phần dư, chu kỳ sẽ đứng im ở 90 micro giây mãi mãi. Đường dốc khựng lại, động cơ không bao giờ đạt được tốc độ đặt. Bảng dưới cho thấy sự khác biệt:

Nhịp | num khi không giữ dư | Kết quả | num khi có giữ dư | Kết quả
400 | 180 | giảm 0 | 180 | giảm 0, để dành 180
401 | 180 | giảm 0 | 360 | giảm 0, để dành 360
405 | 180 | giảm 0 | 1080 | giảm 0, để dành 1080
409 | 180 | giảm 0 mãi mãi | 1800 | **giảm được 1 µs**

uint32_t num = 2U * c + rest; // cộng phần để dành từ lần trước

c -= num / den; // lấy phần nguyên dùng ngay

rest = num % den; // cất phần lẻ lại cho lần sau

Đúng ba dòng, và đây chính là ý tưởng của Bresenham ở chương trước, áp dụng cho một bài toán khác.

## 7.6 Khi đoạn quá ngắn: profile tam giác

Nếu quãng tăng tốc cộng quãng giảm tốc vượt quá chiều dài đoạn thì máy không bao giờ kịp đạt tốc độ đặt. Khi đó phải tính điểm hai dốc gặp nhau và đồ thị trở thành hình tam giác, như nửa phải của Hình 7.

Đây là lý do thực tế khiến in chi tiết nhỏ luôn chậm hơn tốc độ đặt trong phần mềm cắt lớp. Đo trên máy này: đoạn 2 mm đặt 150 mm/s chỉ đạt đỉnh 75 mm/s. Không phải máy yếu, mà là quãng đường quá ngắn để kịp tăng tốc.

## 7.7 Kết quả đo

Lệnh chạy | Tốc độ đỉnh đạt được | Thời gian
100 mm ở 150 mm/s, a = 2000 | 150.6 mm/s | 728 ms
2 mm ở 150 mm/s, a = 2000 | 74.9 mm/s, tam giác | 50 ms
100 mm ở 300 mm/s, a = 5000 | 304.9 mm/s | 406 ms
100 mm ở 600 mm/s | bị từ chối, vượt trần 40 kHz | —

# 8. Bước 5: hàng đợi và nhìn trước

## 8.1 Vấn đề còn lại sau bước 3

Sau chương 7, mỗi lệnh chạy đều bắt đầu từ tốc độ 0 và kết thúc về 0. Với một lệnh dài thì không sao. Nhưng phần mềm cắt lớp sinh ra hàng nghìn đoạn ngắn, và một đường tròn chia thành 72 dây cung sẽ phải dừng hẳn 72 lần. Máy giật, ồn, và chậm gấp ba lần cần thiết.

Nhưng cũng không thể cứ thế chạy thẳng qua mọi điểm nối. Ở một góc vuông, giữ nguyên tốc độ nghĩa là vận tốc đổi hướng tức thời, tương đương gia tốc vô hạn. Thực tế sẽ là một cú giật mạnh, đủ làm mất bước và rung cả khung.

Câu hỏi thật sự là: mỗi điểm nối được phép đi qua ở tốc độ nào?

## 8.2 Tốc độ qua góc

Junction deviation: mô hình do grbl sử dụng. Tưởng tượng đầu in không bẻ góc nhọn mà đi theo một cung tròn nhỏ bo ở góc. Tham số junction deviation là khoảng cách lớn nhất cho phép giữa đường bo đó và góc nhọn lý tưởng, đơn vị milimét. Biết độ lệch cho phép thì suy ra bán kính cung, từ bán kính suy ra tốc độ tối đa để gia tốc hướng tâm không vượt quá giới hạn.

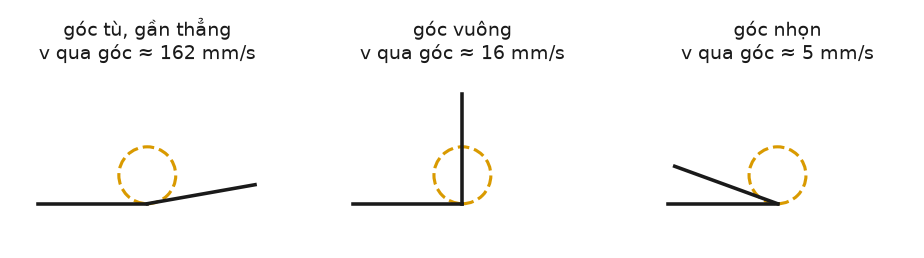
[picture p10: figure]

Hình 10 — Góc càng nhọn thì cung bo càng nhỏ, nên tốc độ cho phép càng thấp. Số liệu tính với junction deviation 0.05 mm và gia tốc 2000 mm/s².

Công thức cuối cùng chỉ cần tích vô hướng của hai vector đơn vị chỉ hướng, không cần tính góc bằng hàm lượng giác:

cos θ = − (vector_trước · vector_sau)

sin(θ/2) = căn(0.5 · (1 − cos θ))

v_góc = căn( a · junction_deviation · sin(θ/2) / (1 − sin(θ/2)) )

Đặt junction deviation lớn thì qua góc nhanh hơn nhưng góc bị bo tròn nhiều hơn. Giá trị 0.05 mm của dự án nằm giữa mức 0.01 mặc định của grbl và các giá trị thường dùng trong máy in 3D.

## 8.3 Hai lượt quét trên hàng đợi

Biết tốc độ cho phép tại từng góc vẫn chưa đủ, vì còn phải bảo đảm tính khả thi vật lý. Không thể vào một đoạn dài 1 mm ở tốc độ 150 mm/s rồi đòi dừng hẳn ở cuối đoạn, vì quãng đường không đủ để phanh.

Vì vậy planner giữ một hàng đợi 32 đoạn, và mỗi khi có đoạn mới được xếp vào, nó quét lại toàn bộ hàng đợi hai lượt:

10. Lượt lùi, từ đoạn cuối về đầu: một đoạn không được vào nhanh hơn mức mà nó còn phanh kịp để khớp với tốc độ vào của đoạn ngay sau. Áp dụng công thức v = căn(v_sau² + 2·a·s).
11. Lượt tới, từ đoạn đầu về cuối: cũng không được vào nhanh hơn mức mà đoạn trước đẩy lên được, cùng công thức nhưng theo chiều ngược lại.

Sau hai lượt, mỗi đoạn có một tốc độ vào vừa thoả mãn giới hạn góc, vừa thoả mãn giới hạn gia tốc ở cả hai phía. Đoạn mà ISR đang chạy không bao giờ bị sửa, vì đường dốc của nó đã khởi động.

Vì sao phải hai lượt: một lượt là không đủ. Quét lùi bảo đảm phanh kịp, nhưng có thể đặt ra tốc độ vào mà đoạn trước không tài nào đẩy lên tới. Quét tới sửa nốt điều đó. Đây là kỹ thuật kinh điển trong mọi planner, từ grbl tới Marlin.

## 8.4 Nối liền hai đoạn trong ngắt

Khi một đoạn kết thúc, ISR nạp luôn đoạn kế tiếp mà không tắt timer. Nhưng công thức AVR446 ở chương 7 giả định đường dốc xuất phát từ đứng yên, trong khi ở đây đoạn mới bắt đầu ở một tốc độ khác 0.

Giải pháp là đặt tốc độ vào và tốc độ ra lên đúng vị trí của chúng trên một đường dốc ảo xuất phát từ 0. Nếu tốc độ vào tương ứng với bước thứ 120 của một đường dốc từ đứng yên, thì bắt đầu đếm từ 120 thay vì từ 0. Hai số bù đó trong code tên là `ioffset` và `joffset`.

i_offset = v_vào² / (2a) vị trí tương đương trên dốc ảo, lúc vào

j_offset = v_ra² / (2a) vị trí tương đương trên dốc ảo, lúc ra

tăng tốc: den = 4 · (số nhịp đã đi + i_offset) + 1

giảm tốc: den = 4 · (số nhịp còn lại + j_offset) + 1

Nhờ vậy công thức truy hồi chạy tiếp liền mạch qua ranh giới hai đoạn, thay vì khởi động lại từ đầu.

## 8.5 Kết quả đo trên máy thật

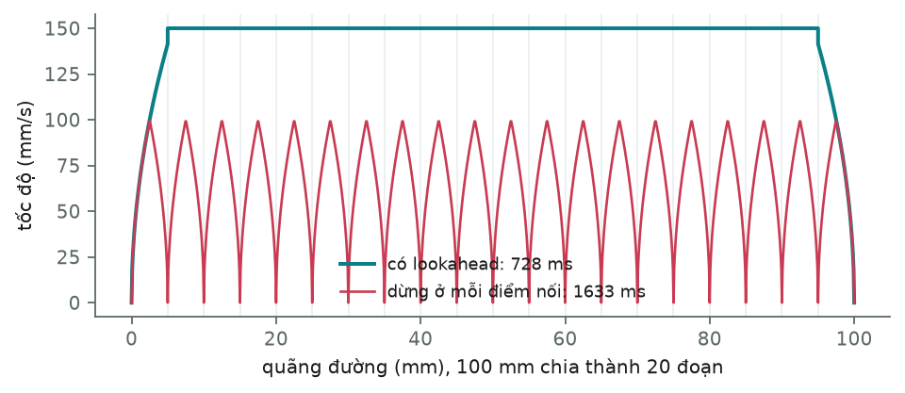
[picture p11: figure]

Hình 11 — Đồ thị tốc độ khi chạy 100 mm chia thành 20 đoạn. Có nhìn trước, máy tăng tốc một lần rồi giữ nguyên. Không có, máy phải dừng hẳn 19 lần.

Cách gửi lệnh | Thời gian | Nguồn số liệu
Một đoạn 100 mm | 728 ms | đo trên máy
Hai mươi đoạn 5 mm | 728 ms | đo trên máy
Hai mươi đoạn, nếu dừng ở mỗi điểm nối | 1633 ms | mô phỏng
Đường tròn bán kính 20 mm, 72 dây cung | nhanh hơn 3.6 lần | mô phỏng

Hai con số đầu bằng nhau tuyệt đối. Đây là kết quả quan trọng nhất của cả dự án: chia nhỏ quãng đường không còn tốn thêm thời gian, nghĩa là firmware đã sẵn sàng nhận dữ liệu thật từ phần mềm cắt lớp.

# 9. Bước 4: đọc lệnh G-code

## 9.1 G-code là gì

G-code: ngôn ngữ điều khiển máy công cụ, ra đời từ thập niên 1950 và được chuẩn hoá thành ISO 6983. Mỗi dòng là một lệnh, gồm các chữ cái kèm số. Chữ cái cho biết loại tham số, số là giá trị. Rất đơn giản về cú pháp, nhưng có đặc tính modal: một thiết lập giữ nguyên hiệu lực cho tới khi bị đổi.

G1 X30 Y20 F6000 đi thẳng tới (30, 20), tốc độ 6000 mm mỗi phút

G1 X40 đi tới X = 40, Y giữ nguyên, tốc độ vẫn 6000

G0 X0 Y0 di chuyển nhanh, dùng khi không in

G2 X30 Y0 I-15 J0 cung tròn thuận chiều kim đồng hồ, tâm lệch (I, J)

G90 / G91 chuyển sang toạ độ tuyệt đối / tương đối

G92 X0 Y0 đặt điểm hiện tại làm gốc, không di chuyển

Một cái bẫy đơn vị: G-code tính tốc độ bằng milimét mỗi phút, còn firmware tính bằng milimét mỗi giây. Parser phải chia cho 60. Quên chi tiết này thì máy chạy nhanh gấp 60 lần lệnh, hậu quả có thể là hỏng cơ khí.

## 9.2 Vì sao cần lớp motion_control riêng

Mọi hình đều quy về đoạn thẳng. Hình vuông là 4 đoạn, đường tròn là 72 đoạn. Bộ phát xung không hề biết nó đang vẽ hình gì, và đó là điều tốt.

Lớp motion_control nằm giữa parser và planner, lo hai việc: giữ vị trí tuyệt đối hiện tại, và chia cung tròn thành các dây cung. Số đoạn không chọn tuỳ tiện mà tính từ sai lệch cho phép:

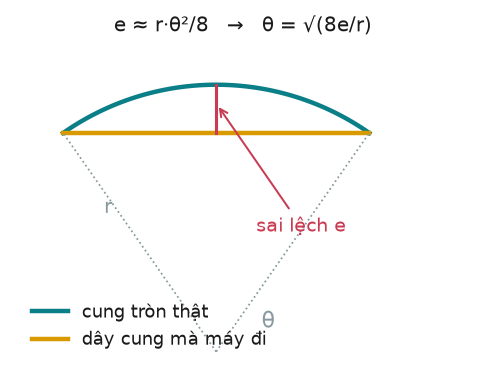
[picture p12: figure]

Hình 12 — Sai lệch e giữa dây cung và cung tròn thật. Từ công thức gần đúng e ≈ r·θ²/8 suy ra góc mỗi đoạn, rồi ra số đoạn.

dung sai dùng trong dự án: 0.002 mm, giống grbl

θ = căn(8 × 0.002 / r)

r = 5 mm → θ = 0.057 rad → 110 đoạn cho một vòng tròn

r = 50 mm → θ = 0.018 rad → 349 đoạn cho một vòng tròn

Cung bán kính lớn tự được chia mịn hơn, đúng như cần. Lưu ý dung sai 0.002 mm nhỏ hơn cả độ phân giải 0.0125 mm của máy, nên về hình học là dư sức.

Minh chứng cho việc tách lớp đúng: khi thêm hỗ trợ cung tròn G2 và G3, file stepper.c không phải sửa một dòng nào. Toàn bộ thay đổi nằm trong motion_control.c và gcode.c.

## 9.3 Bỏ qua thay vì báo lỗi

Parser chấp nhận rồi bỏ qua các chữ Z, E, M, S, T và N. Máy hiện chỉ có hai trục XY, nhưng file thật từ phần mềm cắt lớp luôn chứa lệnh cho trục Z và đầu đùn. Bỏ qua thay vì báo lỗi cho phép chạy thử file thật ngay, và khi nào làm trục Z thì chỉ cần thêm xử lý vào đúng chỗ đó.

## 9.4 Kết quả chạy thật

File thử nghiệm gồm một hình vuông, một ngôi sao năm cánh với các góc rất nhọn, một đường tròn viết bằng một lệnh G2 duy nhất, một hình chữ nhật bo bốn góc bằng cung G3, và một zigzag hai mươi đoạn ngắn.

Chỉ số | Giá trị
Số dòng G-code | 48
Số lỗi cú pháp | 0
Số đoạn thẳng sau khi chia cung | 355
Tổng quãng đường | 799 mm
Thời gian chạy | 9.4 giây
Vùng làm việc | 60 × 63 mm
Vị trí khi kết thúc | đúng gốc, hai bộ đếm motor về 0

# 10. Nhận lệnh qua cổng USB

## 10.1 USB CDC là gì

USB CDC: Communication Device Class, một lớp thiết bị chuẩn của USB. Khi vi điều khiển khai báo mình thuộc lớp này, hệ điều hành tự tạo ra một cổng COM ảo. Phần mềm trên máy tính mở cổng đó và đọc ghi như thể đang dùng cổng nối tiếp RS-232 cổ điển, không cần cài driver riêng. Tốc độ baud khai báo chỉ là hình thức, dữ liệu thực tế chạy ở tốc độ USB.

Lý do chọn CDC thay vì UART thường: không cần mạch chuyển USB sang UART, tốc độ cao hơn nhiều, và cắm thẳng dây USB-C có sẵn trên bo.

## 10.2 Giao thức dòng lệnh

Máy tính gửi từng dòng G-code kết thúc bằng ký tự xuống dòng, bo trả lời `ok` nếu nhận và xếp hàng thành công, hoặc `error` kèm mã lỗi. Ngoài ra có bốn ký tự được xử lý ngay lập tức trong ngắt USB, không đi qua hàng đợi:

Ký tự | Tác dụng | Vì sao phải xử lý ngay
? | báo trạng thái: đang chạy hay rảnh, toạ độ, chỗ trống trong hàng đợi | để hỏi lúc nào cũng được, kể cả khi hàng đợi đầy
! | dừng khẩn: xoá hàng đợi và tắt timer tức thì | nếu xếp hàng thì phải chờ hết mọi lệnh trước, vô nghĩa
~ | bỏ trạng thái dừng khẩn, cho chạy tiếp | đối ứng với lệnh trên
Ctrl-X | reset mềm, đưa mọi thứ về trạng thái đầu | lối thoát cuối cùng khi rối loạn

Chi tiết dễ quên sau khi dừng khẩn: phải kéo vị trí mà planner đang tin về đúng vị trí thật mà động cơ đã dừng. Nếu không, lệnh tiếp theo sẽ tính quãng đường từ một toạ độ sai và đầu in nhảy một cú lớn.

## 10.3 Vì sao không chờ ok từng dòng

Cách đơn giản nhất là gửi một dòng rồi chờ `ok`, xong mới gửi dòng tiếp theo. Cách này sai về mặt hiệu năng, và sai nghiêm trọng.

Lý do: mỗi lần chờ, hàng đợi của planner cạn dần. Khi hàng đợi chỉ còn một đoạn, planner không còn gì để nhìn trước, nên buộc phải giả định đoạn đó là đoạn cuối và cho dừng hẳn ở cuối đoạn. Toàn bộ công sức của chương 8 mất sạch.

Đếm ký tự (character counting): kỹ thuật các script gửi file của grbl dùng. Máy tính biết bộ đệm nhận của bo lớn bao nhiêu byte, ở đây là 256. Nó cứ gửi tiếp chừng nào tổng số byte chưa được xác nhận còn nhỏ hơn 256, và mỗi lần nhận `ok` thì trừ đi độ dài dòng tương ứng. Nhờ vậy trên đường truyền luôn có vài dòng đang bay, và hàng đợi của planner luôn đầy.

## 10.4 Trạng thái hiện tại

Phía vi điều khiển đã kiểm tra xong bằng cách đọc trực tiếp các thanh ghi trên chip đang chạy: clock USB đúng 48 MHz lấy từ bộ nhân tần, nguồn 3.3V riêng cho USB đã sẵn sàng, ngắt đã bật, hàm nhận đã nối vào parser.

Máy tính nhìn thấy có thiết bị cắm vào nhưng chưa đọc được bản mô tả thiết bị, báo lỗi -71. Vì phần vi điều khiển đã được xác nhận đúng, nghi vấn còn lại nằm ở đường dây tín hiệu D+ và D−. Đây là hạng mục duy nhất trong tài liệu chưa hoàn tất.

# 11. Phương pháp làm việc

## 11.1 Mô phỏng trước khi nạp

Thói quen đáng giá nhất của cả dự án: viết lại thuật toán bằng Python và chạy thử trên máy tính trước khi nạp xuống bo, dùng đúng phép toán số nguyên như trong ISR, kể cả phép chia lấy phần nguyên.

Nhờ vậy, cả profile gia tốc lẫn thuật toán nhìn trước đều được kiểm chứng trước khi động cơ quay lần đầu. Khi chạy thật, số đo khớp với mô phỏng tới từng mili giây: mô phỏng 725 ms, đo được 728 ms.

Lợi ích thứ hai, ít ai để ý: mô phỏng trả lời rất nhanh các câu hỏi thiết kế. Đoạn 2 mm ở tốc độ đặt 150 mm/s thực tế đạt bao nhiêu? Chia đường tròn thành bao nhiêu đoạn là đủ? Những câu đó trả lời trong vài giây mà không cần nạp lại firmware.

## 11.2 Thiết kế biến debug cho đúng

Trong lúc tìm lỗi giao tiếp UART, một biến toàn cục ghi lại toàn bộ lần giao tiếp cuối cùng đã giúp phân biệt rõ ràng ba giả thuyết khác nhau:

Số byte nhận được | Kết luận
0 byte | không có cả tiếng vọng, lỗi nằm ở dây hoặc cấu hình chân vi điều khiển
4 byte, đúng bằng gói vừa gửi | tiếng vọng tốt nhưng driver im lặng: lỗi nguồn, địa chỉ, hoặc chân PDN chưa thông
12 byte nhưng nội dung sai | tín hiệu bị méo: lỗi mức điện áp, điện trở, hoặc tốc độ

Nguyên tắc rút ra: biến debug phải phân biệt được các giả thuyết, không chỉ báo thành công hay thất bại. Một biến trả về 'lỗi' không giúp gì. Một biến cho biết nhận được bao nhiêu byte và nội dung ra sao thì thu hẹp phạm vi tìm kiếm ngay lập tức.

## 11.3 Nạp và chạy thử bằng một lệnh

Script `tools/flash_run.sh` đọc địa chỉ biến từ file chương trình bằng công cụ `nm`, nạp firmware, chờ chip khởi động xong rồi ghi thẳng vào ô nhớ để kích hoạt phép thử, sau đó ngắt kết nối để mạch nạp không nằm trên bus khi động cơ chạy.

Ba chi tiết khiến nó hoạt động được:

- Phải chờ sau khi reset rồi mới ghi, vì vùng nhớ dữ liệu bị khởi tạo lại trong lúc chip khởi động, ghi sớm là mất trắng.
- Dùng lệnh ghi một byte cho biến một byte. Ghi cả bốn byte sẽ đè lên các biến nằm kế bên trong bộ nhớ.
- Đọc địa chỉ từ file chương trình mỗi lần chạy, vì địa chỉ thay đổi sau mỗi lần biên dịch.

## 11.4 Quy trình chuẩn cho mỗi bước

12. Viết thuật toán, mô phỏng bằng Python, kiểm tra kết quả có hợp lý không.
13. Viết firmware, biên dịch cho tới khi không còn cảnh báo nào.
14. Nạp và chạy phép thử nhỏ nhất có thể, thường là một chuyển động vài chục milimét ở tốc độ thấp.
15. Đọc biến debug, đối chiếu với kết quả mô phỏng.
16. Chỉ khi hai bên khớp mới lưu lại và chuyển sang bước tiếp theo.

# 12. Tổng hợp lỗi đã gặp

Phần này có giá trị thực dụng cao hơn phần lý thuyết, vì đây là những thứ không có trong sách vở.

Hiện tượng quan sát được | Nguyên nhân thật sự | Bài học rút ra
Driver không trả lời UART | pad UART trên module chưa hàn | tiếng vọng không chứng minh dây đã tới driver
Byte nhận về bị lệch bit | điện trở 10k làm sườn tín hiệu chậm | dùng đúng giá trị nhà sản xuất khuyến nghị
Gửi gói thất bại ngay từ đầu | timeout cố định 5 ms trong khi baud 9600 | mọi thời hạn phải tính theo tham số đang dùng, không để cứng
Gói thứ hai trở đi nhận ra rác | driver giữ bus thêm 4 bit sau khi trả lời | đọc kỹ phần định thời trong datasheet, không chỉ phần định dạng
Động cơ không quay dù hàm báo thành công | đặt tốc độ 2000 mm/s, động cơ rung tại chỗ | giới hạn phải đặt theo khả năng vật lý, không chỉ theo giới hạn CPU
Mất kết nối mạch nạp khi chạy nhanh | nhiễu từ động cơ lọt vào dây SWD | dây debug phải ngắn và xoắn với dây mát
Mất bước ở tốc độ trên 50 mm/s | chưa có gia tốc | pull-in rate là giới hạn vật lý thật, không vượt được bằng phần mềm
Chu kỳ đầu tiên của mỗi lệnh bị sai | thanh ghi ARR có cơ chế preload | đọc kỹ cơ chế nạp giá trị của timer
Máy tính không nhận thiết bị USB | chưa rõ, nghi đường dây D+ và D− | loại trừ từng lớp, bắt đầu từ chỗ đo được

## 12.1 Ba nguyên tắc rút ra

17. Khi có lỗi, đo trước khi sửa code. Toàn bộ lỗi giao tiếp UART đều nằm ở phần cứng hoặc tham số cấu hình. Không có lỗi nào ở thuật toán.
18. Mỗi lớp chỉ nói một thứ tiếng. Lớp trên dùng milimét và số thực, lớp dưới dùng nhịp và số nguyên, và chỉ có đúng một hàm làm nhiệm vụ phiên dịch. Nhờ vậy khi đọc code không bao giờ phải đoán đơn vị.
19. Có số đo cũ thì sửa code mới an toàn. Khi dọn dẹp hai biến đếm thành một, chạy lại đúng hai phép thử cũ và thấy vẫn ra 728 ms là biết ngay không làm hỏng gì. Không có số đo tham chiếu thì mọi lần sửa đều là đánh cược.

# 13. Phụ lục

## 13.1 Thông số máy

Hạng mục | Giá trị
Vi điều khiển | STM32H743IIT6, lõi Cortex-M7, 480 MHz, bo lõi FK743M2
Driver trục X và Y | 2 × TMC2209, điều khiển qua UART một dây, địa chỉ 0 và 1
Cơ cấu truyền động | đai GT2 bước 2 mm, puly 20 răng, 40 mm mỗi vòng
Vi bước | 1/16, có nội suy lên 1/256 bên trong driver
steps_per_mm | 80
Độ phân giải | 0.0125 mm
Timer phát xung | TIM2, một nhịp bằng 1 micro giây
Độ rộng xung STEP | 2 micro giây, do kênh so sánh tạo ra
Trần tốc độ mỗi motor | 40 kHz, tương đương 500 mm/s khi đi thẳng
Gia tốc mặc định | 2000 mm/s²
Junction deviation | 0.05 mm
Dung sai chia cung | 0.002 mm
Độ sâu hàng đợi | 32 đoạn
Bộ đệm nhận lệnh | 256 byte

## 13.2 Các công thức gom lại

ĐỘNG HỌC

ΔA = ΔX + ΔY ΔB = ΔX − ΔY

ΔX = (ΔA + ΔB)/2 ΔY = (ΔA − ΔB)/2

BRESENHAM

n = max(|ΔA|, |ΔB|) err khởi tạo = n/2

err += |Δ|; nếu err ≥ n thì bước và err −= n

QUY ĐỔI ĐƠN VỊ

ticks_per_mm = n / length_mm

v_nhịp = v_mm × ticks_per_mm a_nhịp = a_mm × ticks_per_mm

GIA TỐC

quãng tăng tốc s = v² / (2a)

chu kỳ đầu c0 = F × căn(2/a)

truy hồi c = c − (2c + rest) / (4i + 1)

điểm đỉnh tam giác = (2·a·n + v_ra² − v_vào²) / (4a)

NHÌN TRƯỚC

tốc độ khả thi v = căn(v_trước² + 2·a·s)

tốc độ qua góc v = căn(a · jd · sin(θ/2) / (1 − sin(θ/2)))

CHIA CUNG TRÒN

sai lệch e ≈ r·θ²/8 → θ = căn(8e/r)

## 13.3 Mã nguồn nên đọc tiếp

- grbl, nên đọc đầu tiên vì nhỏ và sáng sủa. File `planner.c` cho phần nhìn trước, `stepper.c` cho phần phát xung, `motion_control.c` cho phần chia cung tròn.
- grblHAL, bản grbl viết lại có lớp trừu tượng phần cứng, có sẵn driver cho dòng STM32H7, hữu ích khi cần tách phần phụ thuộc chip.
- Marlin, phức tạp hơn nhiều nhưng đáng đối chiếu: `planner.cpp` và `stepper.cpp`.
- Klipper, cách tiếp cận hoàn toàn khác: máy tính Linux tính toán, vi điều khiển chỉ phát xung theo lịch đã lập sẵn. Đọc `kinematics/corexy.py` và `chelper/kin_corexy.c`.
- Atmel AVR446, tài liệu gốc của thuật toán gia tốc, và bài báo của David Austin đăng năm 2005 trên Embedded Systems Programming.

## 13.4 Tình trạng dự án

Hạng mục | Trạng thái
Cấu hình TMC2209 qua UART | xong, đã xác nhận trên máy
Phát xung hai motor, động học CoreXY | xong
Gia tốc hình thang | xong
Hàng đợi và nhìn trước | xong
Parser G-code và chia cung tròn | xong
Nhận lệnh qua USB | firmware xong, còn vướng đường dây USB
Về gốc bằng cảm biến tiệm cận | chưa làm
Trục Z và đầu đùn | chưa làm
Đo nhiệt độ và vòng điều khiển PID | chưa làm
Khử rung bằng input shaping | chưa làm
Vẽ mạch in | chưa làm

# Phụ lục A. Đọc code

Phần chính của tài liệu giải thích thuật toán. Phụ lục này đi vào chính những dòng code đang chạy trên máy, giải thích từng khối một, kể cả các cú pháp C mà người mới làm nhúng thường bị vướng.

Cách dùng hiệu quả nhất: mở file nguồn tương ứng bên cạnh và đọc song song.

## A.1 Tám thứ phải hiểu trước khi đọc bất kỳ dòng nào

Toàn bộ firmware chỉ dùng đi dùng lại tám mẫu cú pháp dưới đây. Hiểu một lần là đọc được mọi file.

### 1. static: giới hạn tầm nhìn của biến và hàm

static float pos_x_mm = 0.0f;

static void delay_us(uint32_t us) { ... }

Đặt `static` trước một biến hoặc hàm ở cấp file nghĩa là chỉ file này thấy nó. File khác muốn dùng cũng không được, trình liên kết sẽ báo không tìm thấy.

Vì sao làm vậy: `stepper.c` có khoảng hai mươi biến trạng thái. Nếu để lộ hết ra ngoài thì bất kỳ file nào cũng sửa được, và khi có lỗi phải đi tìm khắp dự án. Để `static` thì phạm vi nghi ngờ thu lại còn đúng một file.

Lưu ý một nghĩa khác của static: khi đặt bên trong một hàm, `static` nghĩa hoàn toàn khác: biến đó giữ giá trị giữa các lần gọi, không bị khởi tạo lại. Ví dụ `static const uint8t addr[2]` trong `tmcsetup()` chỉ được tạo một lần, không phải dựng lại mảng mỗi lần gọi.

### 2. volatile: cấm trình biên dịch khôn lỏi

Đây là từ khoá quan trọng nhất trong lập trình nhúng, và cũng là nguồn lỗi khó tìm nhất khi quên.

Trình biên dịch luôn tìm cách chạy nhanh hơn. Thấy một biến được đọc nhiều lần mà không có lệnh nào ghi vào nó, nó sẽ đọc một lần rồi giữ trong thanh ghi CPU và dùng lại, không thèm đọc lại từ bộ nhớ. Bình thường thì vô hại và nhanh hơn thật.

Nhưng với firmware thì sai, vì có hai thứ ghi vào bộ nhớ mà trình biên dịch không nhìn thấy: ngắt và phần cứng.

// Không có volatile, vòng này có thể chạy mãi mãi:

while (events_left != 0) { }

// Trình biên dịch nghĩ: trong vòng lặp không ai sửa events_left,

// vậy đọc một lần là đủ. Nó dịch thành:

// nạp events_left vào thanh ghi r0

// nếu r0 != 0 thì nhảy về chính nó ← treo vĩnh viễn

// Có volatile, nó buộc phải đọc lại từ RAM mỗi vòng:

static volatile int32_t events_left;

Quy tắc đơn giản: mọi biến mà cả ISR lẫn vòng lặp chính cùng đụng tới đều phải là volatile. Trong `stepper.c`, đó là toàn bộ nhóm biến dưới dòng chú thích `Executor side (ISR)`.

Ngược lại, nhóm biến `Planner side` như `posxmm`, `plan_a` không cần volatile, vì chỉ vòng lặp chính đụng vào. Đánh dấu volatile thừa sẽ làm code chậm đi vô ích.

### 3. Kiểu số có kích thước rõ ràng

Kiểu | Kích thước | Phạm vi | Dùng ở đâu trong dự án
uint8_t | 1 byte | 0 … 255 | chỉ số hàng đợi, cờ bật tắt
int8_t | 1 byte | −128 … 127 | chiều quay, chỉ nhận +1 hoặc −1
int32_t | 4 byte | ±2.1 tỉ | số bước, vị trí, bộ đếm
uint32_t | 4 byte | 0 … 4.3 tỉ | chu kỳ µs, giá trị thanh ghi
float | 4 byte | ~7 chữ số có nghĩa | mm, mm/s, chỉ ở lớp planner

Lý do không dùng `int` trơn: kích thước của `int` phụ thuộc vào chip và trình biên dịch. Trên vi điều khiển, một biến tràn số là một lỗi im lặng, nên phải nói rõ muốn bao nhiêu byte.

Ví dụ cụ thể trong dự án: `int32t posa` đếm vị trí bằng số bước. Với 80 bước mỗi mm, kiểu 32 bit chứa được 26 triệu mm, tức 26 km. Nếu dùng `int16_t` thì chỉ được 409 mm và sẽ tràn ngay.

### 4. struct và con trỏ: dấu chấm hay mũi tên

block_t *b = &queue[q_head]; // b là con trỏ, trỏ tới phần tử trong mảng

b->n = n; // qua con trỏ thì dùng mũi tên

queue[q_head].n = n; // truy cập trực tiếp thì dùng dấu chấm

Hai dòng cuối làm việc giống hệt nhau. Dùng con trỏ chỉ để khỏi phải viết `queue[q_head].` lặp lại hai mươi lần, và để trình biên dịch tính địa chỉ một lần thay vì mỗi dòng một lần.

Ký hiệu `&` trước một biến nghĩa là lấy địa chỉ của nó. `&queue[q_head]` là địa chỉ của phần tử đó trong bộ nhớ.

### 5. Thanh ghi ngoại vi: TIM2->ARR thực chất là gì

Dòng `TIM2->ARR = 83;` trông giống gán cho một trường trong struct, và đúng là như vậy về mặt cú pháp. Nhưng struct đó không nằm trong RAM.

Ánh xạ bộ nhớ (memory mapped I/O): các khối ngoại vi như timer, UART, GPIO được nhà sản xuất gán cho những địa chỉ cố định trong không gian địa chỉ của CPU. Ghi vào địa chỉ đó không phải là lưu dữ liệu, mà là ra lệnh cho phần cứng. Thư viện của ST định nghĩa sẵn một struct đặt đúng vào địa chỉ ấy, nên viết `TIM2->ARR` chính là ghi vào thanh ghi ARR của bộ timer số 2.

// Trong file của ST, rút gọn:

#define TIM2 ((TIM_TypeDef *) 0x40000000UL)

typedef struct {

volatile uint32_t CR1; // offset 0x00

volatile uint32_t CR2; // offset 0x04

volatile uint32_t ARR; // offset 0x2C

} TIM_TypeDef;

// Nên TIM2->ARR = 83 nghĩa là ghi 83 vào địa chỉ 0x4000002C

Để ý mọi trường đều là `volatile`, vì chính phần cứng cũng thay đổi chúng.

### 6. Phép toán bit: bật, tắt, kiểm tra một bit

Một thanh ghi 32 bit thường chứa nhiều công tắc độc lập. Muốn sửa một công tắc mà không đụng các công tắc khác thì phải dùng phép bit.

TIM2->DIER |= TIM_DIER_UIE; // BẬT bit UIE, giữ nguyên các bit khác

TIM2->CR1 &= ~TIM_CR1_CEN; // TẮT bit CEN, giữ nguyên các bit khác

if (sr & TIM_SR_UIF) { ... } // KIỂM TRA bit UIF có đang bật không

Cách viết | Nghĩa | Giải thích
x |= M | bật các bit trong M | hoặc bit: 0|1 = 1, còn bit nào không nằm trong M thì giữ nguyên vì 0|0 = 0
x &= ~M | tắt các bit trong M | `~M` đảo mọi bit của M, nên chỗ cần tắt thành 0, chỗ khác thành 1 và `và` với 1 là giữ nguyên
x & M | kiểm tra | khác 0 nghĩa là có ít nhất một bit trong M đang bật

Các tên như `TIMDIERUIE` là hằng số do ST định nghĩa, bên trong chỉ là một con số có đúng một bit bằng 1. Dùng tên thay vì số giúp đọc hiểu và tránh gõ nhầm.

### 7. BSRR: cách đúng để đổi một chân GPIO trong ngắt

Cách thông thường để đổi một chân là đọc thanh ghi trạng thái, sửa một bit, rồi ghi lại. Ba thao tác, và nguy hiểm: nếu giữa chừng có một ngắt khác cũng sửa chân trên cùng cổng, thay đổi của nó sẽ bị đè mất.

BSRR (Bit Set/Reset Register): thanh ghi đặc biệt chỉ để ghi. 16 bit thấp dùng để bật chân tương ứng, 16 bit cao dùng để tắt. Ghi bit nào bằng 1 thì chân đó đổi, ghi 0 thì không ảnh hưởng. Chỉ một thao tác ghi duy nhất, không đọc, nên không bao giờ bị ngắt chen vào giữa.

A_STEP_PORT->BSRR = A_STEP_PIN; // kéo chân STEP lên 1

A_STEP_PORT->BSRR = (uint32_t)A_STEP_PIN << 16U; // kéo chân STEP xuống 0

Dịch trái 16 bit tức chuyển mặt nạ từ nửa bật sang nửa tắt. Trong ISR của dự án, mọi thao tác chân STEP đều dùng cách này, vừa an toàn vừa nhanh hơn gọi hàm thư viện.

### 8. Ba cú pháp rút gọn hay gặp

dir_a = (da >= 0) ? 1 : -1; // toán tử ba ngôi: if rút gọn

// nếu da >= 0 thì lấy 1, ngược lại lấy -1

int32_t n = (int32_t)lroundf(x); // ép kiểu: buộc đổi sang int32_t

d = num / den; // chia số nguyên: 7/2 = 3, phần lẻ bị cắt

rest = num % den; // lấy phần dư: 7%2 = 1

Cặp `/` và `%` chính là nền tảng của cả Bresenham lẫn thuật toán gia tốc. Phần nguyên dùng ngay, phần dư giữ lại cho lần sau.

## A.2 Bản đồ các file

File | Dòng | Nhiệm vụ | Ai gọi nó
module/stepper.c | ~530 | planner và bộ phát xung, trái tim của firmware | motion_control, và ngắt TIM2
module/motion_control.c | ~90 | giữ vị trí tuyệt đối, chia cung tròn | gcode
module/gcode.c | ~160 | đọc chữ, hiểu lệnh | comms, hoặc vòng chạy job
module/comms.c | ~170 | giao thức dòng lệnh qua USB | ngắt USB, và vòng lặp chính
module/tmc2209.c | ~230 | cấu hình driver qua UART | main lúc khởi động
Core/Src/main.c | ~190 | khởi tạo theo thứ tự, vòng lặp chính | khởi động chip
Core/Src/stm32h7xx_it.c | — | các hàm ngắt, chỉ gọi sang module | phần cứng

Thứ tự nên đọc: `main.c` để thấy toàn cảnh, rồi `stepper.h` để biết giao diện, rồi `stepper.c` từ trên xuống. Ba file còn lại đọc lúc nào cũng được.

## A.3 stepper.h: giao diện nói lên thiết kế

Đọc file header trước khi đọc file nguồn là thói quen tốt: nó cho biết module này hứa làm gì, và giấu đi những gì.

typedef enum {

STEPPER_OK = 0,

STEPPER_BUSY, /* hàng đợi đầy, thử lại sau */

STEPPER_ERROR /* tốc độ ngoài khoảng cho phép */

} stepper_status_t;

stepper_status_t stepper_move_xy(float dx, float dy, float speed);

void stepper_set_accel(float a);

uint8_t stepper_busy(void);

uint8_t stepper_queue_free(void);

void stepper_wait(void);

void stepper_abort(void);

void stepper_tim2_isr(void);

int32_t stepper_pos_a(void);

Ba điều đọc ra được từ đây:

20. Header không include gì của HAL, chỉ `<stdint.h>`. Nghĩa là lớp trên không cần biết chip nào, thư viện nào. Đổi sang chip khác thì chỉ `stepper.c` phải sửa.
21. Trả về mã lỗi thay vì void. Mọi lời gọi đều có thể thất bại, và người gọi buộc phải nhìn thấy điều đó.
22. Có `stepper_queue_free()`. Hàm này tồn tại vì lớp trên cần biết còn bao nhiêu chỗ để quyết định có gửi tiếp hay không, thay vì gửi bừa rồi bị từ chối.

Vì sao `stepper_tim2_isr` lại nằm trong header: hàm ngắt thật sự nằm trong `stm32h7xx_it.c` do CubeMX sinh ra. File đó chỉ gọi sang đây một dòng. Làm vậy để khi CubeMX sinh lại code, phần logic của mình không bị ghi đè.

## A.4 stepper.c, đọc từ trên xuống

### A.4.1 Nhóm hằng số: mỗi con số là một quyết định

#define STEPS_PER_MM 80.0f

#define TIM_TICK_HZ 1000000.0f

#define STEP_PULSE_US 2U

#define MIN_PERIOD_US 25U

#define START_PERIOD_US 2000U

#define DEFAULT_ACCEL 2000.0f

#define DEFAULT_JD 0.05f

#define QUEUE_SIZE 32U

#define QUEUE_MASK (QUEUE_SIZE - 1U)

Hằng số | Vì sao là con số đó
STEPS_PER_MM 80 | từ puly 20 răng và vi bước 1/16, xem mục 1.4
TIM_TICK_HZ 1 MHz | do prescaler 239 trên clock 240 MHz, nên một nhịp là 1 µs
STEP_PULSE_US 2 | driver cần tối thiểu khoảng 100 ns, lấy 2 µs cho chắc
MIN_PERIOD_US 25 | trần 40 kHz mỗi motor, là mức động cơ còn theo được
START_PERIOD_US 2000 | tốc độ khởi động 6 mm/s, chậm hơn nữa là phí thời gian
QUEUE_SIZE 32 | đủ sâu để nhìn trước khi stream đoạn ngắn, mà vẫn ít RAM

Vì sao QUEUE_SIZE phải là luỹ thừa của 2: để phép quay vòng chỉ số làm được bằng phép `và` bit thay vì phép chia lấy dư. Với 32 phần tử, `QUEUE_MASK` bằng 31, tức nhị phân là 11111. Phép `(i + 1) & 31` cho kết quả giống hệt `(i + 1) % 32` nhưng nhanh hơn nhiều, vì phép chia trên vi điều khiển tốn hàng chục chu kỳ còn phép `và` chỉ tốn một.

### A.4.2 block_t: một đoạn chuyển động trông như thế nào

typedef struct {

int32_t steps_a, steps_b; // số bước, luôn dương

int8_t dir_a, dir_b; // chiều, +1 hoặc -1

int32_t n; // số nhịp = max(steps_a, steps_b)

float length_mm; // chiều dài đoạn trong XY

float ux, uy; // vector đơn vị chỉ hướng

float accel;

float nominal_speed; // tốc độ được yêu cầu

float max_entry_speed; // trần do góc nối quyết định

float entry_speed; // tốc độ vào mà planner chốt

} block_t;

Ba trường tốc độ dễ nhầm, nên phân biệt rõ:

- nominal_speed là mong muốn, lấy từ lệnh F trong G-code. Không bao giờ bị sửa.
- max_entry_speed là trần vật lý do hình học góc nối, tính một lần khi đoạn được xếp hàng. Cũng không bị sửa sau đó.
- entry_speed là kết quả cuối cùng sau hai lượt quét. Trường duy nhất bị thay đổi nhiều lần, mỗi khi có đoạn mới vào hàng đợi.

Vector đơn vị: một cặp số (ux, uy) chỉ hướng đi, với độ dài bằng đúng 1. Tính bằng cách chia mỗi thành phần cho chiều dài: `ux = dx / length`. Lưu nó sẵn để sau này tính góc giữa hai đoạn chỉ bằng một phép nhân vô hướng, không phải gọi hàm lượng giác.

### A.4.3 Hàng đợi vòng

static block_t queue[QUEUE_SIZE];

static volatile uint8_t q_head = 0; // nơi planner ghi vào

static volatile uint8_t q_tail = 0; // nơi ISR đang chạy

static uint8_t q_next(uint8_t i) { return (i + 1U) & QUEUE_MASK; }

Hàng đợi vòng (ring buffer): một mảng cố định được dùng như vòng tròn. Khi chỉ số chạm cuối mảng thì quay lại đầu. Nhờ vậy không bao giờ phải cấp phát bộ nhớ động, và không phải dịch chuyển dữ liệu khi lấy phần tử ra.

Hai chỉ số đóng hai vai khác nhau, và đây là điểm mấu chốt về an toàn:

Chỉ số | Ai được sửa | Ý nghĩa
q_head | chỉ vòng lặp chính | ô trống kế tiếp để ghi đoạn mới vào
q_tail | chỉ ISR | đoạn đang được chạy

Mỗi bên chỉ ghi vào chỉ số của riêng mình và chỉ đọc chỉ số của bên kia. Nhờ quy ước này, không cần khoá hay vùng loại trừ cho hàng đợi, hai bên không bao giờ ghi đè nhau.

rỗng: q_head == q_tail

đầy: q_next(q_head) == q_tail // hy sinh một ô để phân biệt

Phải hy sinh một ô vì nếu cho phép dùng hết 32 ô thì trạng thái đầy và trạng thái rỗng đều cho `head == tail`, không phân biệt được. Vì vậy `stepperqueuefree()` trả về tối đa 31 chứ không phải 32.

### A.4.4 Hai nhóm biến trạng thái

Đây là chỗ thể hiện rõ nhất ranh giới kiến trúc của chương 3. Code chia biến thành hai nhóm có chú thích riêng:

Nhóm planner | Nhóm executor (ISR)
`pos_x_mm`, `pos_y_mm` — vị trí đầu in theo lệnh | `pos_a`, `pos_b` — vị trí motor đã chạy thật
`plan_a`, `plan_b` — vị trí motor theo lệnh | `steps_a`, `steps_b`, `err_a`, `err_b` — Bresenham
`prev_ux`, `prev_uy` — hướng đoạn vừa xếp hàng | `c`, `c_min`, `rest` — profile tốc độ
`accel_mm_s2`, `junction_dev` — tham số | `events_left`, `cruise_from`, `decel_from`
**không** volatile, đơn vị mm, số thực | **đều** volatile, đơn vị nhịp, số nguyên

Vì sao có tới hai cặp biến vị trí: `plana` là nơi planner **tin rằng** đầu in sẽ tới sau khi chạy hết hàng đợi. `posa` là nơi motor đang thật sự ở. Khi hàng đợi còn 10 đoạn chưa chạy, hai con số này cách nhau rất xa, và điều đó là bình thường. Chúng chỉ bằng nhau khi hàng đợi rỗng. Lệnh dừng khẩn phải kéo `plana` về bằng `posa`, nếu không toạ độ sẽ sai vĩnh viễn.

### A.4.5 delay_us và bộ đếm chu kỳ

static void delay_us(uint32_t us)

{

uint32_t start = DWT->CYCCNT;

uint32_t ticks = us * (SystemCoreClock / 1000000U);

while ((DWT->CYCCNT - start) < ticks) { }

}

DWT->CYCCNT: một bộ đếm 32 bit nằm trong lõi Cortex-M, tăng đúng một đơn vị mỗi chu kỳ CPU. Ở 480 MHz, nó tăng 480 lần mỗi micro giây. Vốn sinh ra để đo hiệu năng, nhưng dùng làm đồng hồ chính xác rất tiện.

Phép trừ `DWT->CYCCNT - start` hoạt động đúng kể cả khi bộ đếm tràn từ giá trị lớn nhất về 0. Lý do: số học trên kiểu không dấu trong C được định nghĩa là lấy phần dư, nên hiệu vẫn ra đúng khoảng cách. Đây là một mẹo chuẩn mực, không phải may mắn.

Hàm này chỉ được gọi từ vòng lặp chính, cụ thể là lúc chờ chân DIR ổn định. Không bao giờ gọi trong ISR.
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

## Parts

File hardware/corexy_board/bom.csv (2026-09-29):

Ref | Value | Footprint | Qty
C1 | 1000uF/35V | Capacitor_THT:CP_Radial_D13.0mm_P5.00mm | 1
C2,C4,C9,C11,C13,C15,C17 | 100nF/50V | Capacitor_THT:C_Disc_D5.0mm_W2.5mm_P5.00mm | 7
C3,C8,C10,C12,C14,C16 | 100uF/35V | Capacitor_THT:CP_Radial_D8.0mm_P5.00mm | 6
C5 | 470uF/10V | Capacitor_THT:CP_Radial_D8.0mm_P5.00mm | 1
C6,C7,C19,C21,C23,C24,C25,C26,C27,C28,C29 | 100nF | Capacitor_THT:C_Disc_D5.0mm_W2.5mm_P5.00mm | 11
C18,C20 | 1uF | Capacitor_THT:C_Disc_D5.0mm_W2.5mm_P5.00mm | 2
C22 | 10uF/35V | Capacitor_THT:CP_Radial_D5.0mm_P2.00mm | 1
D1 | 1.5KE33CA | Diode_THT:D_DO-201AD_P15.24mm_Horizontal | 1
D2 | LED xanh (24V) | LED_THT:LED_D3.0mm | 1 | mua
D3 | 1.5KE6.8CA | Diode_THT:D_DO-201AD_P15.24mm_Horizontal | 1
D4 | 1N5822 (SS34) | Diode_THT:D_DO-201AD_P15.24mm_Horizontal | 1
D5 | LED xanh (5V) | LED_THT:LED_D3.0mm | 1 | mua
D6 | LED xanh (3V3) | LED_THT:LED_D3.0mm | 1 | mua
D7,D9 | SB560 (SS54) | Diode_THT:D_DO-201AD_P15.24mm_Horizontal | 2
D8 | LED đỏ (hotend) | LED_THT:LED_D3.0mm | 1 | mua
D10 | LED đỏ (bed) | LED_THT:LED_D3.0mm | 1 | mua
D11,D13 | 1N5819 (SS14) | Diode_THT:D_DO-41_SOD81_P10.16mm_Horizontal | 2
D12,D14 | LED xanh | LED_THT:LED_D3.0mm | 2 | mua
D15,D16,D17,D18,D19,D20,D22,D24,D26 | 1N4148 | Diode_THT:D_DO-35_SOD27_P7.62mm_Horizontal | 9 | mua
D21,D23,D25 | LED đỏ | LED_THT:LED_D3.0mm | 3 | mua
F1 | 15A (ATO) | Fuse:Fuseholder_Blade_ATO_Littelfuse_Pudenz_2_Pin | 1 | mua
F2,F3 | 5A (ATO) | Fuse:Fuseholder_Blade_ATO_Littelfuse_Pudenz_2_Pin | 2 | mua
F4 | 2A (Mini) | Fuse:Fuseholder_Blade_Mini_Keystone_3568 | 1 | mua
F5 | PTC 0.5A | Fuse:Fuse_Bourns_MF-RG500 | 1 | mua
FB1 | Ferrite 5A | Ferrite_THT:LairdTech_28C0236-0JW-10 | 1
J1 | XT60 (24V vào) | Connector_AMASS:AMASS_XT60-M_1x02_P7.20mm_Vertical | 1
J2 | FK743M2_P2 | Connector_PinSocket_2.54mm:PinSocket_2x28_P2.54mm_Vertical | 1
J3 | FK743M2_P3 | Connector_PinSocket_2.54mm:PinSocket_2x28_P2.54mm_Vertical | 1
J4 | Motor A (2B 2A 1A 1B) | Connector_JST:JST_XH_B4B-XH-A_1x04_P2.50mm_Vertical | 1
J5 | DIAG A (dây Dupont) | Connector_PinHeader_2.54mm:PinHeader_1x02_P2.54mm_Vertical | 1
J6 | Motor B (2B 2A 1A 1B) | Connector_JST:JST_XH_B4B-XH-A_1x04_P2.50mm_Vertical | 1
J7 | DIAG B (dây Dupont) | Connector_PinHeader_2.54mm:PinHeader_1x02_P2.54mm_Vertical | 1
J8 | Motor Z1 (2B 2A 1A 1B) | Connector_JST:JST_XH_B4B-XH-A_1x04_P2.50mm_Vertical | 1
J9 | Motor Z2 (2B 2A 1A 1B) | Connector_JST:JST_XH_B4B-XH-A_1x04_P2.50mm_Vertical | 1
J10 | Motor E (2B 2A 1A 1B) | Connector_JST:JST_XH_B4B-XH-A_1x04_P2.50mm_Vertical | 1
J11 | HOTEND (+24V, -) | TerminalBlock_Phoenix:TerminalBlock_Phoenix_MKDS-1,5-2-5.08_1x02_P5.08mm_Horizontal | 1
J12 | BED (+24V, -) | TerminalBlock_RND:TerminalBlock_RND_205-00067_1x02_P7.50mm_Horizontal | 1
J13 | FAN PF (+24V, -) | Connector_JST:JST_XH_B2B-XH-A_1x02_P2.50mm_Vertical | 1
J14 | FAN HF (+24V, -) | Connector_JST:JST_XH_B2B-XH-A_1x02_P2.50mm_Vertical | 1
J15 | FAN BOARD (+24V, -) | Connector_JST:JST_XH_B2B-XH-A_1x02_P2.50mm_Vertical | 1
J16 | NTC HOTEND | Connector_JST:JST_XH_B2B-XH-A_1x02_P2.50mm_Vertical | 1
J17 | NTC BED | Connector_JST:JST_XH_B2B-XH-A_1x02_P2.50mm_Vertical | 1
J18 | NTC SPARE | Connector_JST:JST_XH_B2B-XH-A_1x02_P2.50mm_Vertical | 1
J19 | SENSOR X (+24V, GND, SIG) | Connector_JST:JST_XH_B3B-XH-A_1x03_P2.50mm_Vertical | 1
J20 | SENSOR Y (+24V, GND, SIG) | Connector_JST:JST_XH_B3B-XH-A_1x03_P2.50mm_Vertical | 1
J21 | SENSOR Z (+24V, GND, SIG) | Connector_JST:JST_XH_B3B-XH-A_1x03_P2.50mm_Vertical | 1
J22 | FILAMENT (5V, GND, SIG) | Connector_JST:JST_XH_B3B-XH-A_1x03_P2.50mm_Vertical | 1
J23 | SBC UART (TX, RX, GND) | Connector_JST:JST_XH_B3B-XH-A_1x03_P2.50mm_Vertical | 1
JP1,JP2,JP3 | RESET-SLEEP | Connector_PinHeader_2.54mm:PinHeader_1x02_P2.54mm_Vertical | 3
NT1 | NetTie GND-PGND | NetTie:NetTie-2_THT_Pad1.0mm | 1
NT2 | NetTie GND-MGND | NetTie:NetTie-2_THT_Pad1.0mm | 1
Q1 | IRLB3034PbF | Package_TO_SOT_THT:TO-220-3_Vertical | 1
Q2 | IRLB3034PbF (PWM) | Package_TO_SOT_THT:TO-220-3_Vertical | 1
Q3 | IRLB3034PbF (SAFETY) | Package_TO_SOT_THT:TO-220-3_Vertical | 1
Q4,Q5 | AO3400A | Package_TO_SOT_SMD:SOT-23 | 2
R1,R6,R8,R9,R10,R12,R14,R16,R18,R21,R24,R42,R45,R48,R50 | 10k | Resistor_THT:R_Axial_DIN0207_L6.3mm_D2.5mm_P10.16mm_Horizontal | 15
R2,R3,R7,R43,R46,R49,R51 | 1k | Resistor_THT:R_Axial_DIN0207_L6.3mm_D2.5mm_P10.16mm_Horizontal | 7
R4 | 100k 1% | Resistor_THT:R_Axial_DIN0207_L6.3mm_D2.5mm_P10.16mm_Horizontal | 1
R5 | 10k 1% | Resistor_THT:R_Axial_DIN0207_L6.3mm_D2.5mm_P10.16mm_Horizontal | 1
R11,R13,R15,R26,R29 | 100 | Resistor_THT:R_Axial_DIN0207_L6.3mm_D2.5mm_P10.16mm_Horizontal | 5
R17,R20,R23 | 22 | Resistor_THT:R_Axial_DIN0207_L6.3mm_D2.5mm_P10.16mm_Horizontal | 3
R19,R25,R28,R31 | 4.7k | Resistor_THT:R_Axial_DIN0207_L6.3mm_D2.5mm_P10.16mm_Horizontal | 4
R22,R27,R30 | 100k | Resistor_THT:R_Axial_DIN0207_L6.3mm_D2.5mm_P10.16mm_Horizontal | 3
R32,R35,R38 | 4.7k 1% | Resistor_THT:R_Axial_DIN0207_L6.3mm_D2.5mm_P10.16mm_Horizontal | 3
R33,R34,R36,R37,R39,R40 | 2.37k 1% | Resistor_THT:R_Axial_DIN0207_L6.3mm_D2.5mm_P10.16mm_Horizontal | 6
R41,R44,R47 | 1.5k 0.5W | Resistor_THT:R_Axial_DIN0309_L9.0mm_D3.2mm_P12.70mm_Horizontal | 3
TP1 | VIN_24V | TestPoint:TestPoint_THTPad_D1.5mm_Drill0.7mm | 1
TP2 | +5V | TestPoint:TestPoint_THTPad_D1.5mm_Drill0.7mm | 1
TP3 | +5V_KIT | TestPoint:TestPoint_THTPad_D1.5mm_Drill0.7mm | 1
TP4 | +3V3 | TestPoint:TestPoint_THTPad_D1.5mm_Drill0.7mm | 1
TP5 | GND | TestPoint:TestPoint_THTPad_D1.5mm_Drill0.7mm | 1
TP6 | PGND | TestPoint:TestPoint_THTPad_D1.5mm_Drill0.7mm | 1
TP7 | MGND | TestPoint:TestPoint_THTPad_D1.5mm_Drill0.7mm | 1
TP8 | A_STEP | TestPoint:TestPoint_THTPad_D1.5mm_Drill0.7mm | 1
TP9 | A_DIR | TestPoint:TestPoint_THTPad_D1.5mm_Drill0.7mm | 1
TP10 | B_STEP | TestPoint:TestPoint_THTPad_D1.5mm_Drill0.7mm | 1
TP11 | B_DIR | TestPoint:TestPoint_THTPad_D1.5mm_Drill0.7mm | 1
TP12 | Z1_STEP | TestPoint:TestPoint_THTPad_D1.5mm_Drill0.7mm | 1
TP13 | Z2_STEP | TestPoint:TestPoint_THTPad_D1.5mm_Drill0.7mm | 1
TP14 | E_STEP | TestPoint:TestPoint_THTPad_D1.5mm_Drill0.7mm | 1
TP15 | TMC_UART | TestPoint:TestPoint_THTPad_D1.5mm_Drill0.7mm | 1
TP16 | SPARE_DRV | TestPoint:TestPoint_THTPad_D1.5mm_Drill0.7mm | 1
TP17 | HE_NEG | TestPoint:TestPoint_THTPad_D1.5mm_Drill0.7mm | 1
TP18 | BED_NEG | TestPoint:TestPoint_THTPad_D1.5mm_Drill0.7mm | 1
TP19 | BED_MID | TestPoint:TestPoint_THTPad_D1.5mm_Drill0.7mm | 1
TP20 | X_HOME | TestPoint:TestPoint_THTPad_D1.5mm_Drill0.7mm | 1
TP21 | Y_HOME | TestPoint:TestPoint_THTPad_D1.5mm_Drill0.7mm | 1
TP22 | Z_PROBE | TestPoint:TestPoint_THTPad_D1.5mm_Drill0.7mm | 1
U1 | LM2596S module (chỉnh 5.2V) |  | 1
U2 | MKS TMC2209 (A) | Module:Pololu_Breakout-16_15.2x20.3mm | 1
U3 | MKS TMC2209 (B) | Module:Pololu_Breakout-16_15.2x20.3mm | 1
U4 | A4988 (Z1) | Module:Pololu_Breakout-16_15.2x20.3mm | 1
U5 | A4988 (Z2) | Module:Pololu_Breakout-16_15.2x20.3mm | 1
U6 | A4988 (E) | Module:Pololu_Breakout-16_15.2x20.3mm | 1
U7,U8 | TC4427CPA | Package_DIP:DIP-8_W7.62mm | 2
U9,U10,U11 | PC817 | Package_DIP:DIP-4_W7.62mm | 3

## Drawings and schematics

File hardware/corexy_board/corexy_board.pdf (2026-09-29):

1 | 2 | 3 | 4 | 5 | 6 | 7 | 8

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
Size: A3 | Rev: 0.1 | F Date: 2026-09-16
KiCad E.D.A. 10.0.6 | Id: 1/8

## Title: Bo điều khiển máy in 3D CoreXY

### File: corexy_board.kicad_sch

### Sheet: /

### Sinh tự động bởi hardware/tools/gen_schematic.py

04_Heater File: 04_Heater.kicad_sch

### 07_IO

File: 07_IO.kicad_sch 05_Quat File: 05_Quat.kicad_sch | 02_MCU
File: 02_MCU.kicad_sch | 03_Driver File: 03_Driver.kicad_sch 06_NTC

File: 06_NTC.kicad_sch 01_Nguon

File: 01_Nguon.kicad_sch | Kit MCU FANKE FK743M2-IIT6 (STM32H743IIT6) cắm qua 2 header 2x28 BO ĐIỀU KHIỂN MÁY IN 3D COREXY — STM32H743 + 2xTMC2209 + 3xA4988 — 24V

QUYẾT ĐỊNH THIẾT KẾ (chi tiết: docs/01_kinh_nghiem_tu_mach_tham_khao.md, mục 9) - Nguồn 24V qua XT60. 3 nhánh cầu chì: bed 15A / hotend+quạt 5A / motor+logic 5A. - 3 net GND: GND (logic), PGND (công suất), MGND (motor) nối 1 điểm bằng NetTie ở trang Nguồn. - Buck module 5.2V -> 1N5822 -> 5V của kit (chống USB cấp ngược vào máy tính). - Heater: IRLB3034 lái bởi TC4427 @5V. Bed có MOSFET an toàn nối tiếp (BED_SAFETY mặc định TẮT). - Driver: A, B = MKS TMC2209 V2.0 (UART PDN, địa chỉ 0/1). Z1, Z2, E = A4988 1/16 bước. - Homing X/Y/Z: cảm biến tiệm cận NPN 24V, cách ly PC817. Logic MCU: kích hoạt = mức THẤP. - Quạt 2 dây: part fan PWM, hotend fan bật/tắt, quạt bo luôn bật.

Lưu ý khi lắp bo thử: - Chỉnh áp ra buck 5.2V TRƯỚC khi nối vào mạch. - Chỉnh Vref A4988 Z1 và Z2 bằng nhau. - AO3400A là SOT-23 (SMD): hàn lên đế chuyển SOT-23 sang DIP. - Symbol linh kiện THT thay cho bản SMD dự kiến trên PCB: 1.5KE33CA~SMBJ28A, 1N5822~SS34, SB560~SS54, 1N5819~SS14.

Quạt 24V 2 dây: làm mát chi tiết (PWM), tản nhiệt hotend (bật/tắt), quạt bo (luôn bật)

Nguồn 24V: bảo vệ, cầu chì, buck 5V, nối GND

Đo nhiệt độ NTC 100k B3950 (mạch giống SKR 2 / Octopus / Prusa Buddy)

GÁN CHÂN MCU (STM32H743IIT6 trên kit FK743M2-IIT6)

PD3 | -> A_STEP | (TMC2209 A)
PD4 | -> A_DIR
PA15 | -> XY_EN | (EN chung A+B)
PD7 | -> A_DIAG
PG9 | -> B_STEP
PG10 | -> B_DIR
PG11 | -> B_DIAG
PE3 | -> Z1_STEP
PE4 | -> Z1_DIR
PB3 | -> Z1_EN
PF6 | -> Z2_STEP
PF7 | -> Z2_DIR
PF8 | -> Z2_EN
PB12 | -> E_STEP
PB13 | -> E_DIR
PB7 | -> E_EN
PB10 | -> TMC_UART_TX | (USART3_TX (qua 1k))
PB11 | -> TMC_UART | (USART3_RX = bus UART)
PC0 | -> TH_HOTEND | (ADC)
PC1 | -> TH_BED
PC4 | -> TH_SPARE
PB8 | -> HOTEND_PWM | (TIM4_CH3)
PB9 | -> BED_PWM | (TIM4_CH4)
PA4 | -> BED_SAFETY
PB14 | -> PART_FAN_PWM | (TIM12_CH1)
PB15 | -> HOTEND_FAN_EN
PA6 | -> X_HOME
PA7 | -> Y_HOME
PC7 | -> Z_PROBE
PC6 | -> FIL_RUNOUT
PC5 | -> VIN_SENSE | (ADC, 24V/11)
PA0 | -> SBC_TX | (UART4_TX)
PA1 | -> SBC_RX | (UART4_RX)
Cảm biến homing NPN 24V (cách ly PC817), cảm biến hết nhựa, UART cho | SBC
Driver động cơ: A, B = TMC2209 (MKS V2.0, UART) | Z1, Z2, E = A4988 | Heater: hotend + bàn nhiệt (IRLB3034 lái bởi TC4427 @5V) + ngắt an toàn bàn nhiệt

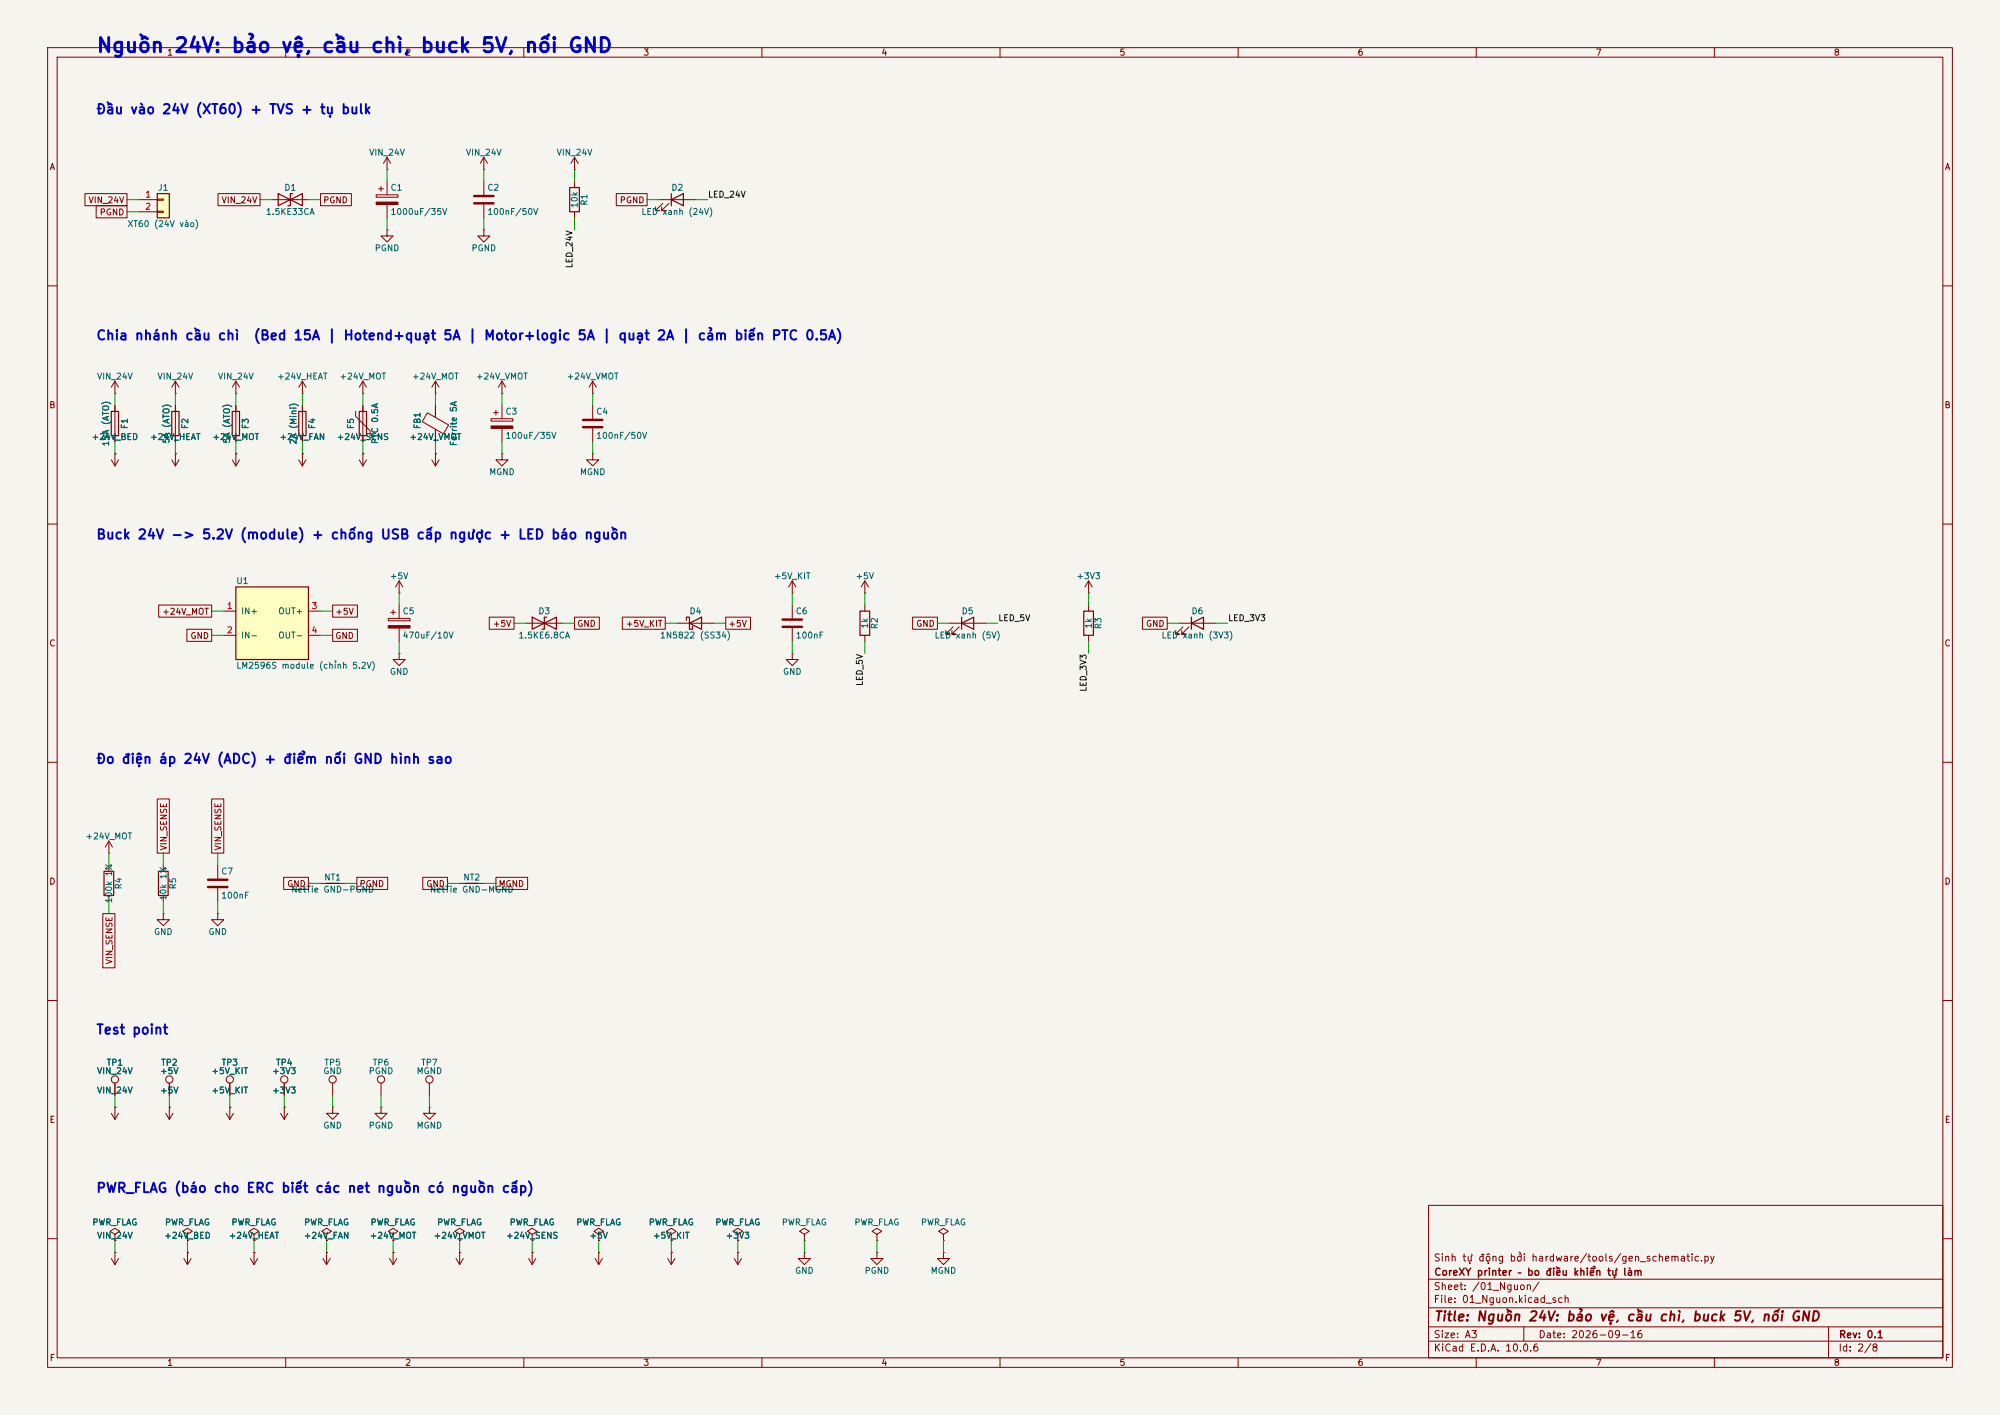
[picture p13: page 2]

Nguồn 24V: bảo vệ, cầu chì, buck 5V, nối GND

Đầu vào 24V (XT60) + TVS + tụ bulk

Chia nhánh cầu chì (Bed 15A | Hotend+quạt 5A | Motor+logic 5A | quạt 2A | cảm biến PTC 0.5A)

Buck 24V -> 5.2V (module) + chống USB cấp ngược + LED báo nguồn

LED_3V3 Đo điện áp 24V (ADC) + điểm nối GND hình sao

PWR_FLAG (báo cho ERC biết các net nguồn có nguồn cấp)

CoreXY printer – bo điều khiển tự làm
Sheet: /01_Nguon/
File: 01_Nguon.kicad_sch
Title: Nguồn 24V: bảo vệ, cầu chì, buck 5V, nối GND

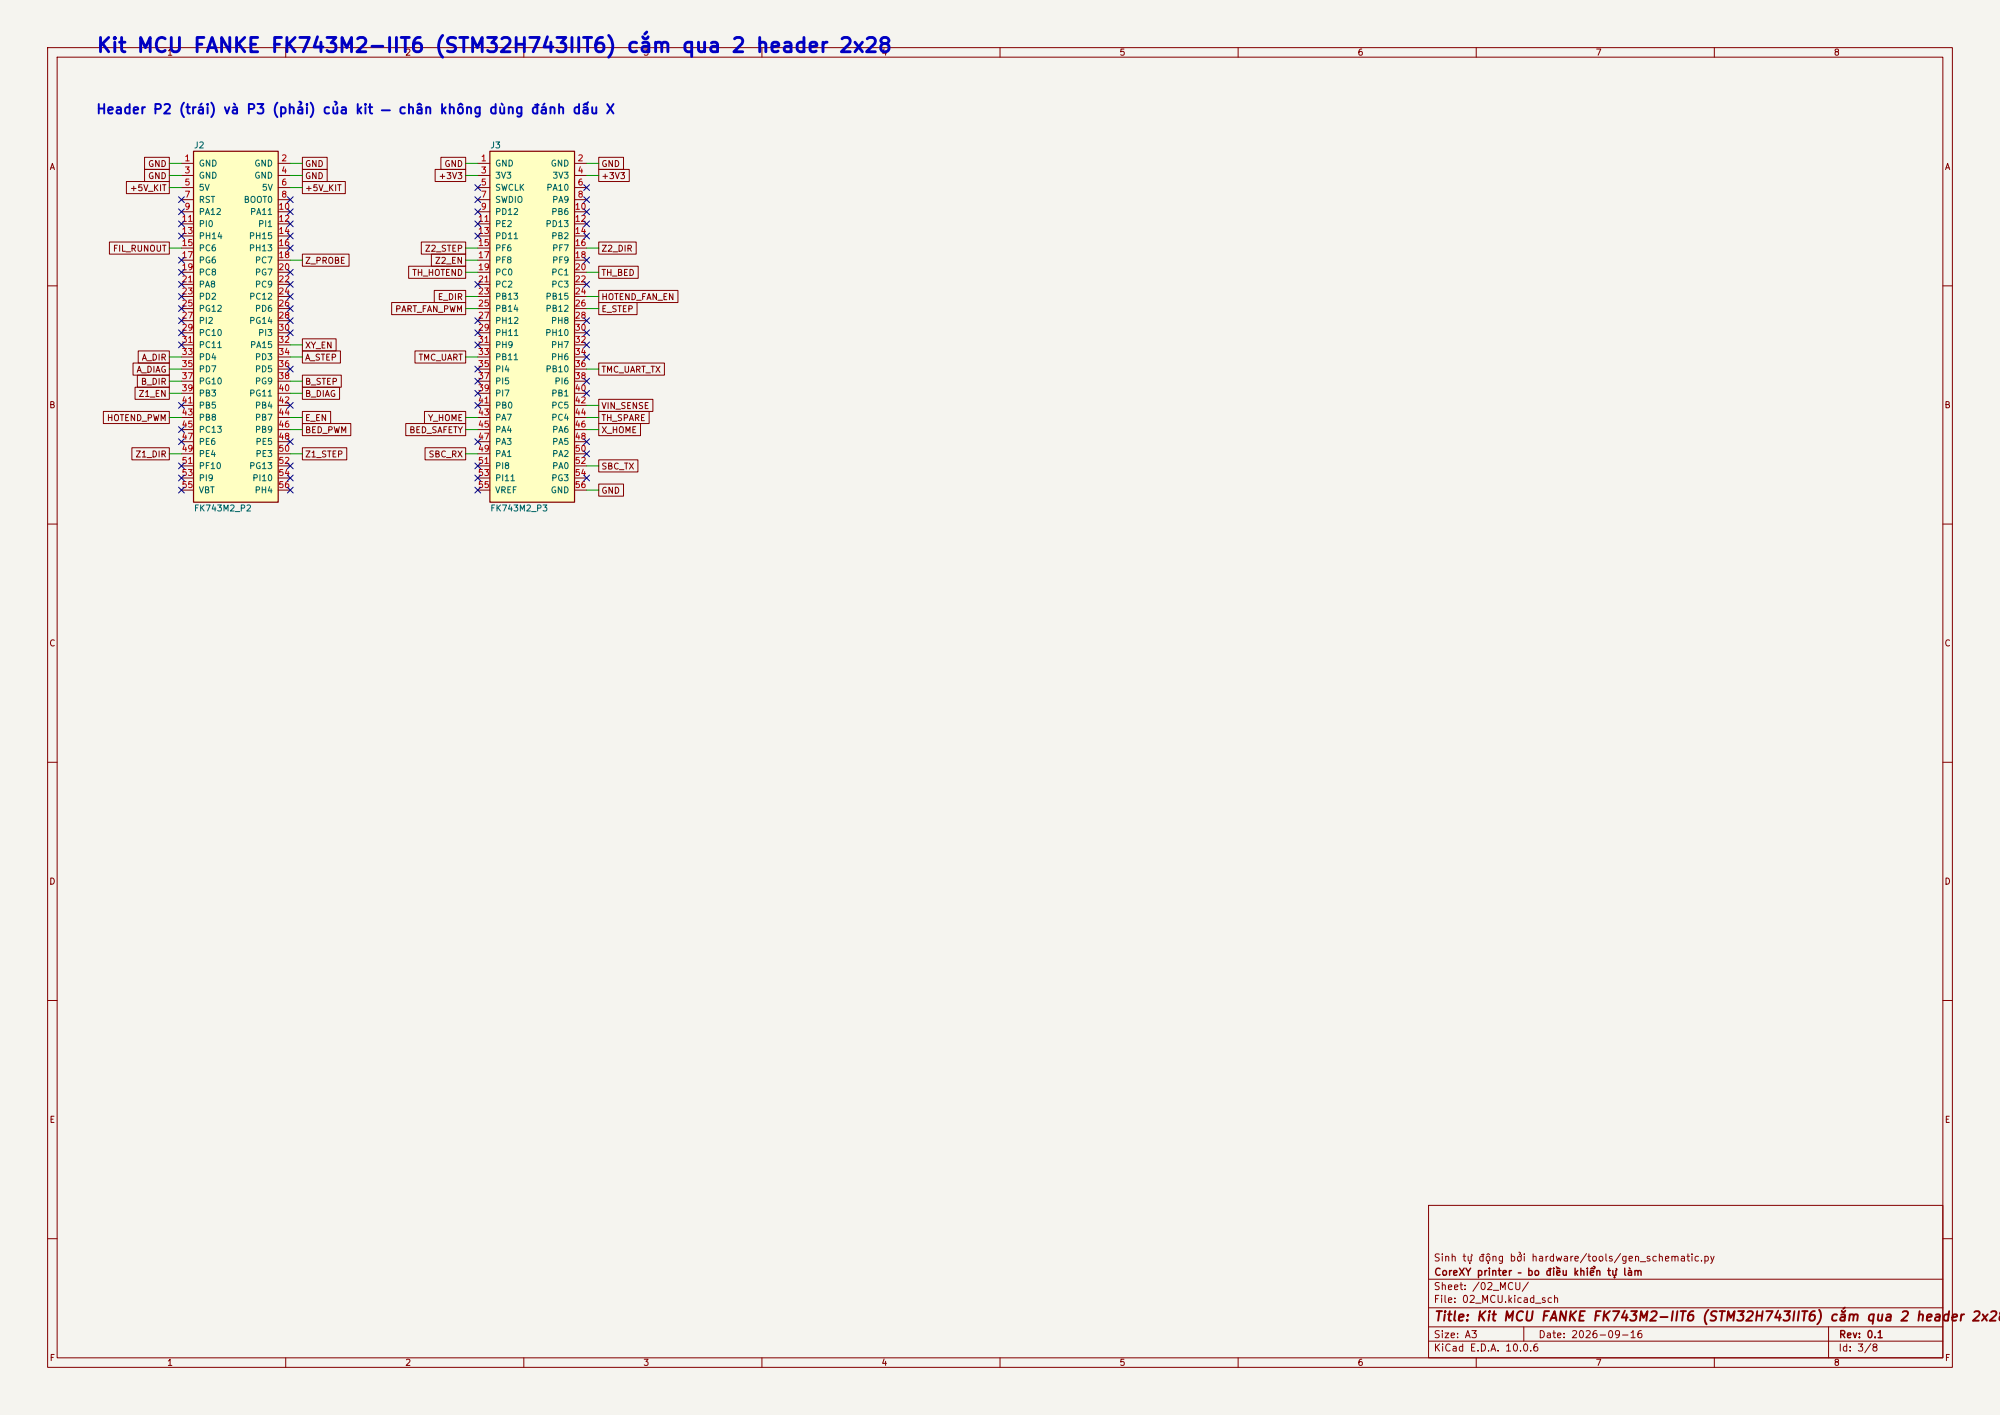
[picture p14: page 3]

Kit MCU FANKE FK743M2-IIT6 (STM32H743IIT6) cắm qua 2 header 2x28

BED_SAFETY XY_EN Header P2 (trái) và P3 (phải) của kit — chân không dùng đánh dấu X

Sinh tự động bởi hardware/tools/gen_schematic.py
CoreXY printer – bo điều khiển tự làm
Sheet: /02_MCU/
File: 02_MCU.kicad_sch
Title: Kit MCU FANKE FK743M2-IIT6 (STM32H743IIT6) cắm qua 2 header 2x28

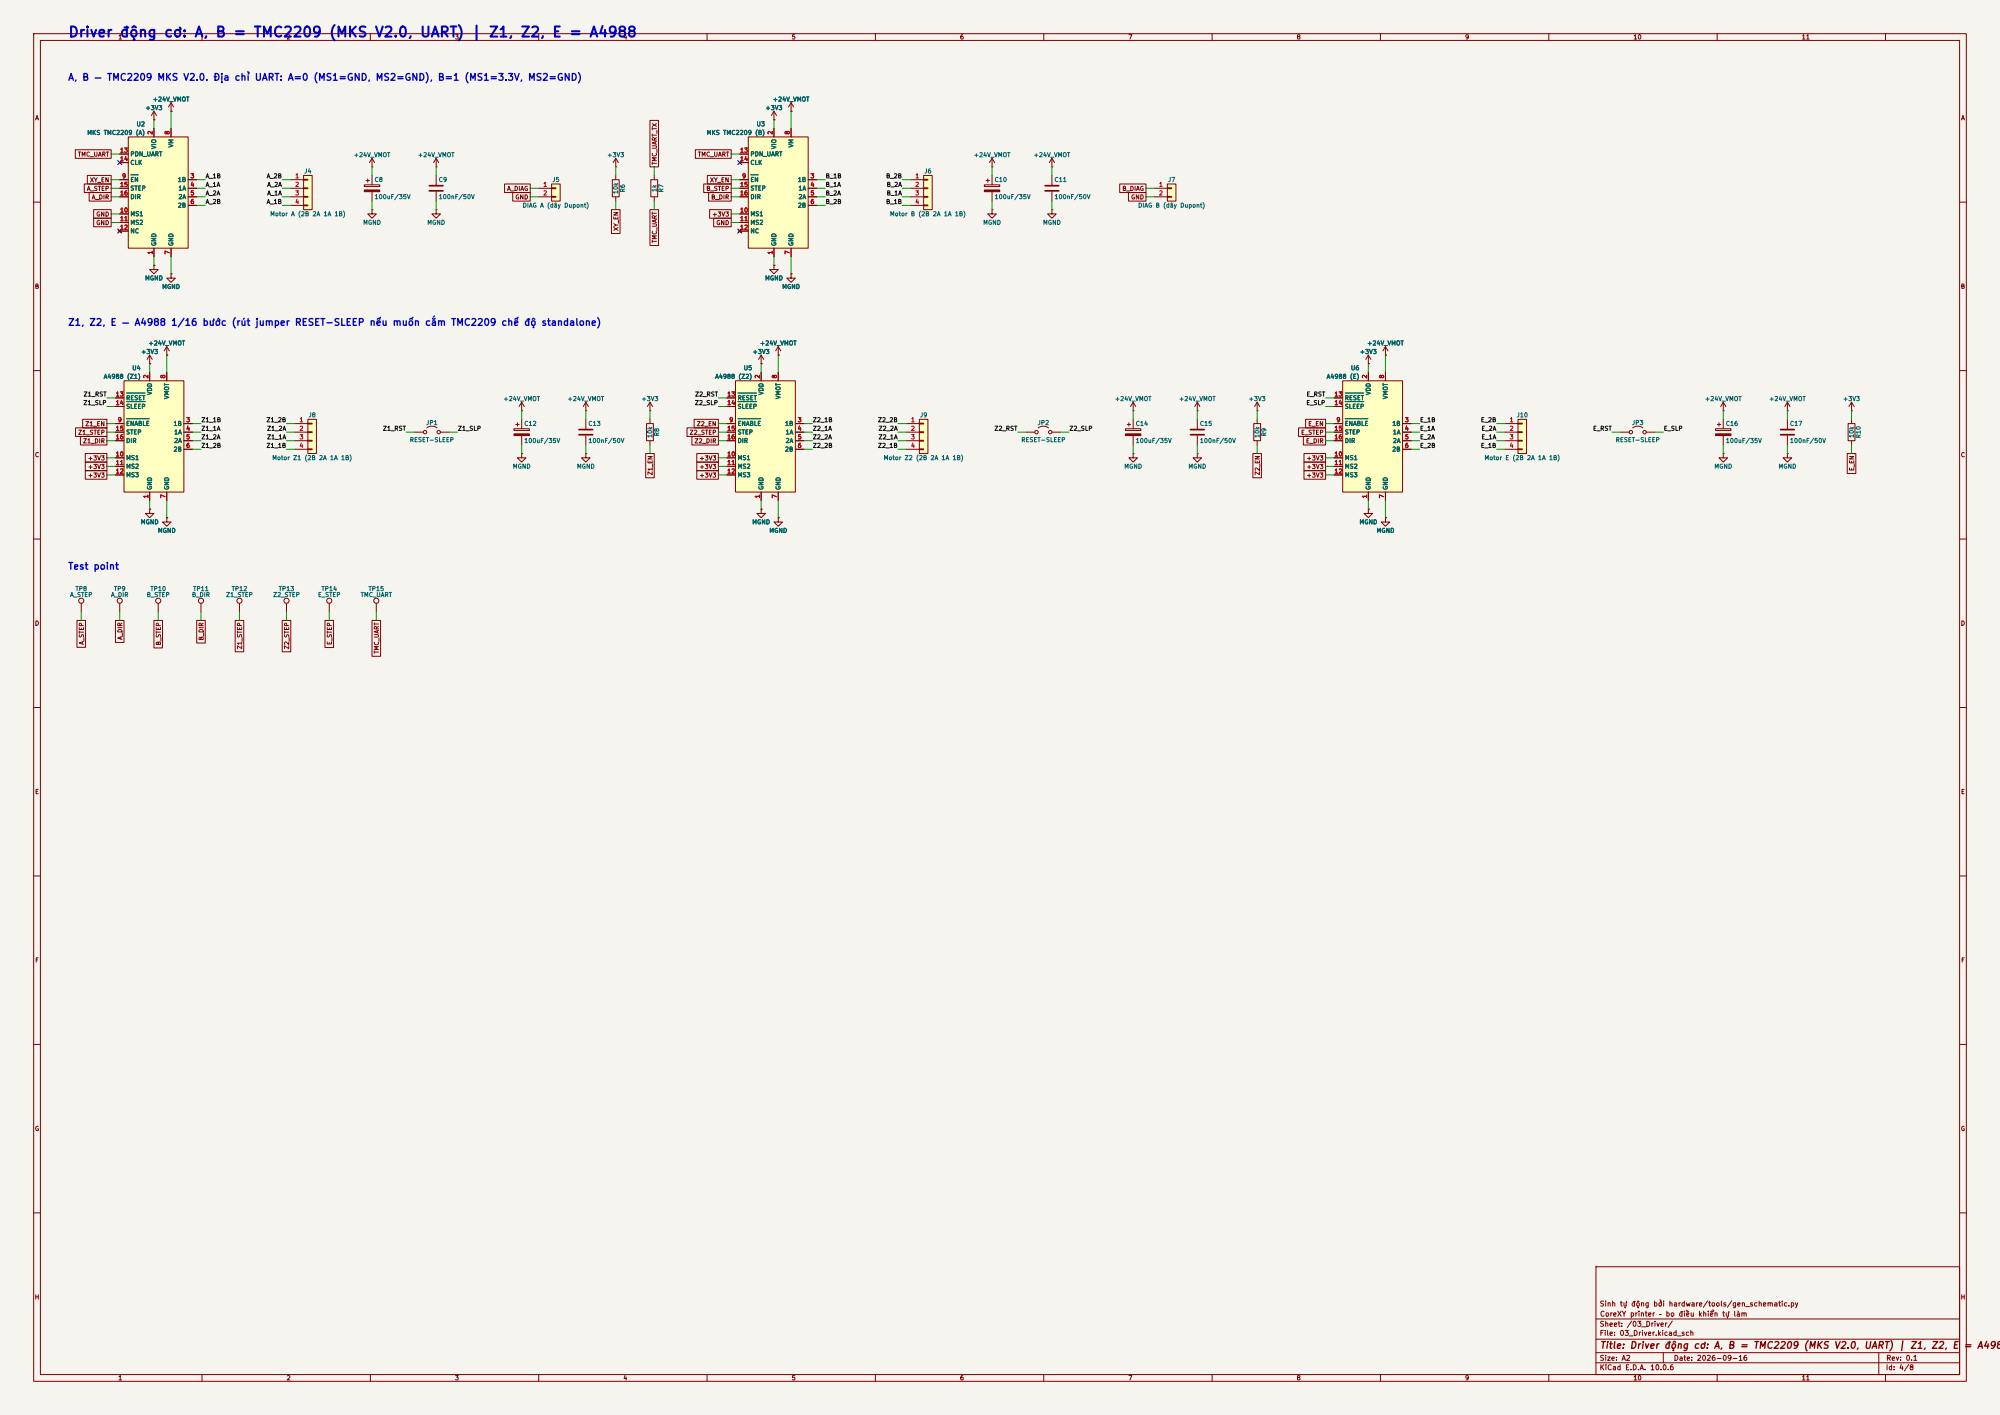
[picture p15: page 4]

Driver động cơ: A, B = TMC2209 (MKS V2.0, UART) | Z1, Z2, E = A4988

A, B — TMC2209 MKS V2.0. Địa chỉ UART: A=0 (MS1=GND, MS2=GND), B=1 (MS1=3.3V, MS2=GND)

E_1A Z1, Z2, E — A4988 1/16 bước (rút jumper RESET-SLEEP nếu muốn cắm TMC2209 chế độ standalone)
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

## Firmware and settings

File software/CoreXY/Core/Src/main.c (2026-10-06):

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
/* Includes ------------------------------------------------------------------*/
#include "main.h"
#include "tim.h"
#include "usart.h"
#include "usb_device.h"
#include "gpio.h"

/* USER CODE BEGIN Includes */
#include "tmc2209.h"
#include "stepper.h"
#include "gcode.h"
#include "gcode_job.h"
#include "comms.h"
/* USER CODE END Includes */

/* USER CODE BEGIN PD */
#define MICROSTEPS_XY         16U
/* USER CODE END PD */


/* USER CODE BEGIN PV */
/* Result of tmc2209_init: [0] = motor A (addr 0), [1] = motor B (addr 1) */
volatile tmc2209_status_t tmc_status[2];

/* Test hook. Nothing moves on its own: set step_test_run from the debugger
 * (or tools/flash_run.sh). Distance in whole mm, speed in mm/s. */
volatile uint8_t  step_test_run = 0;         /* one straight move */
volatile uint8_t  step_test_split = 0;       /* same distance, 20 queued segments */
volatile uint32_t step_test_ms = 0;          /* how long the last test took */

/* G-code job baked into flash by tools/gcode_to_header.py */
volatile uint8_t  gcode_job_run = 0;
volatile uint32_t gcode_job_line = 0;        /* line being run */
volatile int32_t  gcode_job_errors = 0;
volatile gcode_status_t gcode_job_last = GCODE_OK;
volatile int32_t  step_test_dx = 20;         /* mm */
volatile int32_t  step_test_dy = 0;          /* mm */
volatile int32_t  step_test_speed = 20;      /* mm/s */
volatile int32_t  step_test_accel = 2000;    /* mm/s^2 */
volatile stepper_status_t step_test_status = STEPPER_OK;
/* USER CODE END PV */

void SystemClock_Config(void);
static void MPU_Config(void);
/* USER CODE BEGIN 0 */
static void tmc_setup(void)
{
  static const uint8_t addr[2] = { TMC2209_ADDR_A, TMC2209_ADDR_B };

  for (uint8_t i = 0; i < 2; i++)
    tmc_status[i] = tmc2209_init(addr[i], MICROSTEPS_XY);
}
/* USER CODE END 0 */

/**
  * @brief  The application entry point.
  * @retval int
  */
int main(void)
{

  /* MPU Configuration--------------------------------------------------------*/
  MPU_Config();

  /* MCU Configuration--------------------------------------------------------*/

  /* Reset of all peripherals, Initializes the Flash interface and the Systick. */
  HAL_Init();

  /* Configure the system clock */
  SystemClock_Config();

  /* Initialize all configured peripherals */
  MX_GPIO_Init();
  MX_USART3_UART_Init();
  MX_TIM2_Init();
  MX_USB_DEVICE_Init();
  /* USER CODE BEGIN 2 */
  HAL_Delay(100);   /* let the drivers power up (VM must be on) */
  tmc_setup();
  stepper_init();
  gcode_init();
  comms_init();
  /* USER CODE END 2 */

  /* Infinite loop */
  /* USER CODE BEGIN WHILE */
  while (1)
  {
    /* USER CODE END WHILE */

    /* USER CODE BEGIN 3 */
    comms_task();

    if (step_test_run)
    {
      step_test_run = 0;
      stepper_set_accel((float)step_test_accel);
      uint32_t t0 = HAL_GetTick();
      step_test_status = stepper_move_xy((float)step_test_dx,
                                         (float)step_test_dy,
                                         (float)step_test_speed);
      stepper_wait();
      step_test_ms = HAL_GetTick() - t0;
    }

    /* Run the G-code job stored in flash, line by line. */
    if (gcode_job_run)
    {
      gcode_job_run = 0;
      gcode_job_errors = 0;
      stepper_set_accel((float)step_test_accel);
      uint32_t t0 = HAL_GetTick();

      for (uint32_t i = 0; i < GCODE_JOB_LINES; i++)
      {
        gcode_job_line = i;
        gcode_job_last = gcode_line(gcode_job[i]);
        if (gcode_job_last != GCODE_OK && gcode_job_last != GCODE_EMPTY)
          gcode_job_errors++;
      }
      stepper_wait();
      step_test_ms = HAL_GetTick() - t0;
    }

    /* Same distance as step_test_run, but fed as 20 short segments. With
     * lookahead the two should take the same time. */
    if (step_test_split)
    {
      step_test_split = 0;
      stepper_set_accel((float)step_test_accel);
      const uint8_t parts = 20;
      float sx = (float)step_test_dx / (float)parts;
      float sy = (float)step_test_dy / (float)parts;
      uint32_t t0 = HAL_GetTick();

      for (uint8_t i = 0; i < parts; i++)
      {
        /* the queue holds 15, so wait for room instead of dropping moves */
        while (stepper_queue_free() == 0)
        {
        }
        step_test_status = stepper_move_xy(sx, sy, (float)step_test_speed);
        if (step_test_status != STEPPER_OK)
          break;
      }
      stepper_wait();
      step_test_ms = HAL_GetTick() - t0;
    }
  }
  /* USER CODE END 3 */
}

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
 /* MPU Configuration */

void MPU_Config(void)
{
  MPU_Region_InitTypeDef MPU_InitStruct = {0};

  /* Disables the MPU */
  HAL_MPU_Disable();

  /** Initializes and configures the Region and the memory to be protected
  */
  MPU_InitStruct.Enable = MPU_REGION_ENABLE;
  MPU_InitStruct.Number = MPU_REGION_NUMBER0;
  MPU_InitStruct.BaseAddress = 0x0;
  MPU_InitStruct.Size = MPU_REGION_SIZE_4GB;
  MPU_InitStruct.SubRegionDisable = 0x87;
  MPU_InitStruct.TypeExtField = MPU_TEX_LEVEL0;
  MPU_InitStruct.AccessPermission = MPU_REGION_NO_ACCESS;
  MPU_InitStruct.DisableExec = MPU_INSTRUCTION_ACCESS_DISABLE;
  MPU_InitStruct.IsShareable = MPU_ACCESS_SHAREABLE;
  MPU_InitStruct.IsCacheable = MPU_ACCESS_NOT_CACHEABLE;
  MPU_InitStruct.IsBufferable = MPU_ACCESS_NOT_BUFFERABLE;

  HAL_MPU_ConfigRegion(&MPU_InitStruct);
  /* Enables the MPU */
  HAL_MPU_Enable(MPU_PRIVILEGED_DEFAULT);

}

/**
  * @brief  This function is executed in case of error occurrence.
  * @retval None
  */
void Error_Handler(void)
{
  /* USER CODE BEGIN Error_Handler_Debug */
  /* User can add his own implementation to report the HAL error return state */
  __disable_irq();
  while (1)
  {
  }
  /* USER CODE END Error_Handler_Debug */
}
#ifdef USE_FULL_ASSERT
/**
  * @brief  Reports the name of the source file and the source line number
  *         where the assert_param error has occurred.
  * @param  file: pointer to the source file name
  * @param  line: assert_param error line source number
  * @retval None
  */
void assert_failed(uint8_t *file, uint32_t line)
{
  /* USER CODE BEGIN 6 */
  /* User can add his own implementation to report the file name and line number,
     ex: printf("Wrong parameters value: file %s on line %d\r\n", file, line) */
  /* USER CODE END 6 */
}
#endif /* USE_FULL_ASSERT */

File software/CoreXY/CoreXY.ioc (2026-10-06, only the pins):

Mcu.UserName=STM32H743IITx
PA11.Signal=USB_OTG_FS_DM
PA12.Signal=USB_OTG_FS_DP
PB10.Signal=USART3_TX
PB11.Signal=USART3_RX
PD3.GPIO_Label=STEP_A_PUL
PD3.Signal=GPIO_Output
PD4.GPIO_Label=STEP_A_Dir
PD4.Signal=GPIO_Output
PG10.GPIO_Label=STEP_B_DIR
PG10.Signal=GPIO_Output
PG9.GPIO_Label=STEP_B_PUL
PG9.Signal=GPIO_Output
PH7.GPIO_Label=LED_OB
PH7.Signal=GPIO_Output

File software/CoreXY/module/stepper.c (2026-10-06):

#include "stepper.h"
#include "main.h"
#include "tim.h"
#include "motion_control.h"
#include <math.h>

/* GT2 belt, 20 tooth pulley, 1/16 microstepping */
#define STEPS_PER_MM      80.0f

/* TIM2 runs at 1 MHz (prescaler 239 on a 240 MHz timer clock), so one tick
 * is one microsecond and ARR is the step period in us. */
#define TIM_TICK_HZ       1000000.0f
#define STEP_PULSE_US     2U       /* TMC2209 needs ~100 ns, 2 us is safe */
#define MIN_PERIOD_US     25U      /* 40 kHz per motor: what a NEMA17 follows */
#define START_PERIOD_US   2000U    /* slowest period used, ~6 mm/s */
#define DEFAULT_ACCEL     2000.0f  /* mm/s^2 */
#define DEFAULT_JD        0.05f    /* junction deviation, mm */

#define QUEUE_SIZE        32U      /* must be a power of two */
#define QUEUE_MASK        (QUEUE_SIZE - 1U)

#define A_STEP_PORT       STEP_A_PUL_GPIO_Port
#define A_STEP_PIN        STEP_A_PUL_Pin
#define B_STEP_PORT       STEP_B_PUL_GPIO_Port
#define B_STEP_PIN        STEP_B_PUL_Pin

/* ------------------------------------------------------------------ */
/* Queue                                                               */
/* ------------------------------------------------------------------ */

typedef struct
{
  int32_t steps_a, steps_b;    /* magnitudes */
  int8_t  dir_a, dir_b;
  int32_t n;                   /* Bresenham events = steps of the busiest motor */

  float length_mm;
  float ux, uy;                /* unit vector of the move in XY */
  float accel;                 /* mm/s^2 */

  float nominal_speed;         /* mm/s, what was asked for */
  float max_entry_speed;       /* mm/s, limit set by the corner */
  float entry_speed;           /* mm/s, what the planner settled on */
} block_t;

static block_t queue[QUEUE_SIZE];
static volatile uint8_t q_head = 0;   /* where the planner writes */
static volatile uint8_t q_tail = 0;   /* what the ISR is running */

static uint8_t q_next(uint8_t i) { return (uint8_t)((i + 1U) & QUEUE_MASK); }

/* ------------------------------------------------------------------ */
/* State                                                               */
/* ------------------------------------------------------------------ */

/* Planner side (main context only) */
static float pos_x_mm = 0.0f, pos_y_mm = 0.0f;   /* commanded head position */
static int32_t plan_a = 0, plan_b = 0;           /* commanded motor position, steps */
static float prev_ux = 0.0f, prev_uy = 0.0f;     /* direction of the last queued move */
static uint8_t have_prev = 0;
static float accel_mm_s2 = DEFAULT_ACCEL;
static float junction_dev = DEFAULT_JD;

/* Executor side (ISR) */
static volatile int32_t steps_a = 0, steps_b = 0;
static volatile int32_t err_a = 0, err_b = 0;
static volatile int32_t event_count = 0;
static volatile int32_t events_left = 0;
static volatile int8_t  dir_a = 1, dir_b = 1;
static volatile int32_t pos_a = 0, pos_b = 0;    /* executed position, steps */
static volatile uint8_t running = 0;
static volatile uint8_t stopping = 0;            /* last pulse still high */

/* Speed profile of the block being executed, in timer ticks */
static volatile uint32_t c = 0;          /* current period, us */
static volatile uint32_t c_min = 0;      /* period at cruise speed */
static volatile uint32_t rest = 0;       /* remainder of the integer divide */
/* Both thresholds are expressed in events_left, the one counter the
 * Bresenham loop already keeps, so there is no second index to keep in
 * step with it (grbl does the same). */
static volatile int32_t  cruise_from = 0;   /* ramp up   while events_left >  this */
static volatile int32_t  decel_from = 0;    /* ramp down while events_left <= this */
static volatile int32_t  i_offset = 0;      /* virtual ramp index at entry speed */
static volatile int32_t  j_offset = 0;      /* virtual ramp index at exit speed */

static void delay_us(uint32_t us)
{
  uint32_t start = DWT->CYCCNT;
  uint32_t ticks = us * (SystemCoreClock / 1000000U);
  while ((DWT->CYCCNT - start) < ticks)
  {
  }
}

/* ------------------------------------------------------------------ */
/* Planner                                                             */
/* ------------------------------------------------------------------ */

/* Speed reachable after accelerating over `distance` starting at v0. */
static float speed_after(float v0, float accel, float distance)
{
  return sqrtf(v0 * v0 + 2.0f * accel * distance);
}

/* Two passes over the queued blocks, grbl style. Backwards first: a block
 * may not enter faster than it can still brake down to the entry speed of
 * the one after it. Then forwards: it may not enter faster than the
 * previous block can accelerate it to. The block being executed is left
 * alone — its ramp is already running. */
static void recalculate(void)
{
  if (q_head == q_tail)
    return;

  uint8_t first = q_tail;
  if (running)
    first = q_next(q_tail);        /* do not touch what the ISR is running */
  if (first == q_head)
    return;

  /* backward pass */
  uint8_t i = q_head;
  float next_entry = 0.0f;         /* the queue ends at standstill */
  while (i != first)
  {
    i = (uint8_t)((i + QUEUE_MASK) & QUEUE_MASK);   /* i-- */
    block_t *b = &queue[i];
    float reachable = speed_after(next_entry, b->accel, b->length_mm);
    float v = b->max_entry_speed;
    if (reachable < v) v = reachable;
    if (b->nominal_speed < v) v = b->nominal_speed;
    b->entry_speed = v;
    next_entry = v;
    if (i == first)
      break;
  }

  /* forward pass */
  uint8_t prev = first;
  i = q_next(first);
  while (i != q_head)
  {
    block_t *p = &queue[prev];
    block_t *b = &queue[i];
    float reachable = speed_after(p->entry_speed, p->accel, p->length_mm);
    if (reachable < b->entry_speed)
      b->entry_speed = reachable;
    prev = i;
    i = q_next(i);
  }
}

/* Corner speed from the junction deviation model (grbl). A straight joint
 * keeps full speed, a hairpin drops to nearly zero. */
static float junction_speed(const block_t *b)
{
  if (!have_prev)
    return 0.0f;                    /* first move starts from standstill */

  float cos_theta = -(prev_ux * b->ux + prev_uy * b->uy);
  if (cos_theta > 0.999999f)
    return 0.0f;                    /* reversal: must stop */
  if (cos_theta < -0.999999f)
    return b->nominal_speed;        /* straight on */

  float sin_half = sqrtf(0.5f * (1.0f - cos_theta));
  if (sin_half >= 0.999999f)
    return 0.0f;
  return sqrtf(b->accel * junction_dev * sin_half / (1.0f - sin_half));
}
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

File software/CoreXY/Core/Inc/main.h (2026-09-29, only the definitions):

#define LED_OB_Pin GPIO_PIN_7
#define LED_OB_GPIO_Port GPIOH
#define STEP_A_PUL_Pin GPIO_PIN_3
#define STEP_A_PUL_GPIO_Port GPIOD
#define STEP_A_Dir_Pin GPIO_PIN_4
#define STEP_A_Dir_GPIO_Port GPIOD
#define STEP_B_PUL_Pin GPIO_PIN_9
#define STEP_B_PUL_GPIO_Port GPIOG
#define STEP_B_DIR_Pin GPIO_PIN_10
#define STEP_B_DIR_GPIO_Port GPIOG

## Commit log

2026-09-29 CoreXY printer: KiCad schematic, docs and STM32H743 firmware
    Hardware: generated KiCad schematic for the controller board
    (hardware/corexy_board, generator in hardware/tools).
    Firmware (software/CoreXY, STM32H743 / FK743M2, CubeMX + CMake):
    - module/tmc2209: single-wire UART driver for the two CoreXY
    TMC2209s (addresses 0 and 1 via MS1/MS2), sets GCONF, CHOPCONF
    MRES and NODECONF, verifies writes through IFCNT. Timeout and
    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
    [01_Nguon.kicad_sch, 02_MCU.kicad_sch, 03_Driver.kicad_sch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]
2026-09-29 Step generation: TIM2 + Bresenham for both CoreXY motors
    - module/stepper: stepper_move_xy() takes a straight line in XY, applies
    the CoreXY transform (A = X+Y, B = X-Y) and drives both motors from one
    TIM2 tick with Bresenham, so they start and finish together. Targets are
    computed from the absolute position so rounding never accumulates, and
    the tick rate comes from the XY length, not from A/B.
    - The ISR never waits: the update event raises the STEP pins and compare
    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
2026-09-29 Docs: README, step generation notes and project checklist
    - README.md: hardware, pin map, folder layout, build/flash commands,
    current state and what the firmware borrows ideas from.
    - docs/timer.md: how the step generator works — CoreXY kinematics, TIM2
    at 1 MHz, the update/compare interrupt pair, Bresenham, the three
    traps (last pulse, ARR preload, absolute targets), CPU budget, and why
    1/16 microstepping with interpolation stays.
    - docs/checklist.md: what is done and what is left, step by step, plus
    the hardware lessons from the hand-built prototype and the loose ends
    (untested speed limit, UART baud back to 115200, HAL FIFO gotcha).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
2026-10-06 Trapezoidal acceleration for every move
    - stepper: each move now ramps up, cruises and ramps down. The profile is
    worked out in timer ticks before the move starts (sqrt stays out of the
    ISR); the ISR only runs the AVR446 recurrence c -= 2c/(4i+1) and writes
    ARR, which is preloaded so the new period applies to the next step.
    Short moves fall back to a triangle and never reach the asked speed.
    - A remainder term keeps the integer divide from drifting.
    - MIN_PERIOD_US raised 5 -> 25 us: a 40 kHz per-motor ceiling the motors
    can actually follow, so a nonsense speed now returns STEPPER_ERROR
    instead of silently stalling.
    - stepper_set_accel(), default 2000 mm/s^2.
    - main/tools: step_t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
    [main.c, stepper.c]
2026-10-06 Lookahead: 16-block queue, junction speeds, no stop between moves
    Planner (main loop, floats):
    - stepper_move_xy now queues a block and returns. Each block keeps its
    unit vector, length, nominal speed and the corner limit.
    - Corner speed from grbl's junction deviation model, tunable with
    stepper_set_junction_deviation(), default 0.05 mm.
    - Two passes on every new block: backwards (a block may not enter faster
    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
2026-10-06 G-code parser, motion_control layer and a demo job
    - module/gcode: G0, G1, G2, G3, G4, G90, G91, G92, G21 and F. Z, E, M, S,
    T and N are parsed and ignored so slicer output still runs on an XY-only
    machine; ';' and '(...)' comments are stripped. Feed arrives in mm/min
    and is kept in mm/s.
    - module/motion_control: owns the absolute position and turns arcs into
    chords short enough for a 0.002 mm sag, the same idea as grbl's mc_arc.
    The stepper layer never learns an arc existed.
    - tools/make_gcode.py writes a demo job (square, star, G2 circle, rounded
    rectangle, zigzag) and tools/gcode_to_header.py bakes a .gcode file into
    module/gcode_job.h, which is how a job reaches the board u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
    [gcode_to_header.py, main.c, make_gcode.py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]
2026-10-06 USB CDC command stream, and one counter instead of two in the ISR
    - module/comms: line protocol over USB CDC. "ok" or "error:<n>" per line,
    and four characters acted on the moment they arrive: '?' status, '!'
    stop and clear the queue, '~' resume, Ctrl-X reset. The host keeps
    several lines in flight and counts characters, the way grbl's senders
    do, so the planner always has something to look ahead over; waiting for
    "ok" line by line would drain the queue and undo the lookahead.
    - stepper_abort() for '!': halts the timer, drops the queue and then
    pulls the planner position back to where the motors actually stopped.
    - Queue grown 16 -> 32 blocks, which matters when streaming short m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
    [CoreXY.ioc, main.c, send_gcode.py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]
2026-10-06 Docs: training document (Word) covering the whole firmware
    docs/CoreXY_firmware_tai_lieu_dao_tao.docx — a teaching write-up in
    Vietnamese, aimed at someone who can write C but has never done motion
    control. Every concept is introduced where it is first needed, with the
    real numbers from this machine.
    Contents: stepper motors, STEP/DIR, microstepping and steps/mm, timers
    and interrupts; CoreXY kinematics and where the sqrt(2) comes from; the
    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
2026-10-06 Docs: rewrite the training document with figures and fuller explanations
    The first version named concepts without teaching them. This one defines
    every term where it first appears and shows the mechanism with a figure.
    - 12 generated figures (docs/make_training_figs.py): STEP/DIR waveform
    against motor position, microstep current sines, the CoreXY belt
    schematic, the four basic moves with their ΔA/ΔB, a square drawn in XY
    and the same square in motor coordinates, a Bresenham run plotted tick
    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
2026-10-06 Docs: appendix that walks through the actual source
    The main document explains the algorithms; this appendix explains the
    code that implements them, for someone who can write C but has not done
    embedded work before.
    - A.1 covers the eight C and embedded idioms the firmware keeps reusing,
    each with the concrete reason it is there: static, volatile (with the
    while loop that hangs without it), sized integer types, struct
    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
2026-10-06 Docs: how to study the material, and a set of exercises
    Section 0.3 turns the document into something you work through rather
    than read: three rules (read with the source open, predict before you
    measure, break things on purpose), an eight-session route that says
    which chapter to read, which file to open, what to do and how to tell
    you understood it, three self-checks, and the four ways self-teaching
    firmware usually goes wrong.
    Appendix B is the practice:
    - B.2, ten predict-then-measure runs with the real commands and the
    measured answers. Two of them are deliberately counter-intuitive:
    raising acceleration 2.5x on a long move buys only 3%, and the same
    speed that runs fine along X i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
2026-10-06 Docs: two-day study schedule, system before code
    Section 0.4 lays out the first two days. It also states the reading
    order explicitly, because that order matters: system (ch. 1-3), then
    what each stage solves (ch. 4-10), and only then the code appendix.
    Reading code before the system gives you a pile of disconnected
    details; the other way round each line has somewhere to attach.
    Day one is the system: read chapters 1-3, then trace one line of
    G-code ("G1 X10 Y10 F3000") through every stage and fill in an empty
    table saying what each stage receives, what it turns it into and which
    units it works in. Day two reads chapters 4-10 for the problem each
    stage solves, skipping their code, and runs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

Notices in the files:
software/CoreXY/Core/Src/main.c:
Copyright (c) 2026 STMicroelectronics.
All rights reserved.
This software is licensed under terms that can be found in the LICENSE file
